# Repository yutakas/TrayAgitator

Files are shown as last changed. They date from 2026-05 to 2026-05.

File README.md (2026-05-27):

# TrayAgitator

A timer-controlled **tray agitator** driven by an ESP32-S3 and a stepper motor.
It runs the motor in an intermittent **2 s on / 8 s off** cycle for a set
duration, with adjustable agitation strength, a countdown timer, an OLED UI, and
buzzer feedback — handy for tasks like film/print development, PCB etching, or
staining where a tray needs gentle, periodic agitation.

## Features

- **Countdown timer** settable in 10-second, minute, and hour steps (up to 5 h).
- **Adjustable strength** (0–4) — controls the stepper's step rate.
- **Intermittent agitation**: the motor rotates ~2 s, then rests ~8 s, repeating
  for the whole run.
- **OLED UI** (SSD1306 128×64) showing mode, time, strength, and chip temperature.
- **DONE screen**: when the timer finishes it shows `DONE!` and counts up the
  time elapsed since it finished; press START to reset.
- **Cancel gesture**: hold MODE + START together to stop a running timer.
- **Persistent settings**: timer and strength are saved to NVS and restored on boot.
- **Boot diagnostics**: shows the last reset reason (and whether a run was active)
  on the OLED and serial, to help track down power/reboot issues. WiFi is disabled
  to reduce power spikes.

## Hardware

- **MCU:** Waveshare **ESP32-S3 Zero** (powered from USB-C, 5 V; 3V3 taken from its
  3V3 pad for the OLED and driver logic).
- **Stepper driver:** **A4988** (motor supply `VMOT` = 8–35 V, e.g. 12 V, with a
  100 µF cap across VMOT–GND).
- **Motor:** bipolar 4-wire NEMA-style stepper.
- **Display:** SSD1306 OLED, 128×64, I²C @ `0x3C`.
- **Buzzer:** passive buzzer.
- **Input:** 4 push buttons (`INPUT_PULLUP`, 50 ms debounce).

### Pin map

| GPIO | Function | Connects to |
|---|---|---|
| 3 | UP button | button → GND |
| 4 | DOWN button | button → GND |
| 5 | MODE button | button → GND |
| 6 | START button | button → GND |
| 7 | Buzzer | passive buzzer + GND |
| 8 | I²C SDA | OLED SDA |
| 9 | I²C SCL | OLED SCL |
| 10 | Stepper STEP | A4988 STEP |
| 11 | Stepper DIR | A4988 DIR |
| 12 | Stepper ENABLE  | A4988 EN (see note) |

**Wiring notes**

- All grounds must be common: ESP32 GND, A4988 logic GND, motor-supply (−), OLED,
  buzzer, and button returns.
- The A4988 `EN` pin is active-LOW on the chip, but the firmware drives EN **HIGH
  to run** / LOW to idle — verify your physical EN wiring/logic matches.
- Tie A4988 `RESET` to `SLEEP`; set `MS1/MS2/MS3` for the desired microstep mode.
- The MODE button idles LOW while the others idle HIGH (per a firmware comment) —
  confirm that switch's normally-open/closed wiring.

See [Documents/](Documents/) for the full diagrams:
[wiring](Documents/TrayAgitator-wiring.svg),
[schematic](Documents/TrayAgitator-schematic.svg) (KiCad source
`TrayAgitator.kicad_sch`), and the `TrayAgitator Build Doc.docx`.

## Controls

- **MODE** cycles the setting screen: `Set 10 sec` → `Set Min` → `Set Hours` →
  `Strength`.
- **UP / DOWN** adjust the current setting (only while the timer is stopped):
  time by 10 s / 1 min / 1 h, or strength 0–4.
- **START**:
  - stopped → start the run (if a time is set)
  - running → pause
  - paused → resume
  - done → acknowledge and return to the setting screen
- **MODE + START (held together)** → cancel a running/paused timer.

## Build & flash

The firmware lives in [ESP32_Source/](ESP32_Source/) and builds with
[PlatformIO](https://platformio.org/).

```bash
cd ESP32_Source
pio run            # build
pio run -t upload  # flash over USB (serial/esptool — more reliable than JTAG)
pio device monitor # serial monitor @ 115200
```

- **Environment:** `esp32-s3-devkitc-1` (Arduino framework), used as the build
  target for the S3 board.
- **Key dependencies** (auto-installed by PlatformIO): Adafruit SSD1306,
  ezButton, AccelStepper. See [ESP32_Source/platformio.ini](ESP32_Source/platformio.ini).

> On macOS, prefer `pio run -t upload` (serial) over JTAG programming — the
> built-in USB-JTAG can be unreliable for flashing.

## Project structure

```
TrayAgitator/
├── ESP32_Source/        # PlatformIO firmware project
│   ├── src/main.cpp     # all firmware logic
│   └── platformio.ini   # board / build config
├── Documents/           # KiCad schematic, wiring/schematic SVGs, build doc
└── README.md
```

## Notes

- The current build **pauses at boot** on the reset-reason screen until a button
  is pressed — this is a debugging aid and can be removed for normal use.
- Some warmth on the chip-temperature readout is normal (it reads the silicon die
  temperature, above ambient).

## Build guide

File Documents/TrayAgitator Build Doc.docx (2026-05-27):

ESP32 Pins

Pin3 Up button

Pin4 Down Button

Pin5 Mode Button

Pin6 Start Button

Pin8 I2C SDA

Pin9 I2C SCL

ESP32 S3 Zero

https://www.waveshare.com/wiki/ESP32-S3-Zero

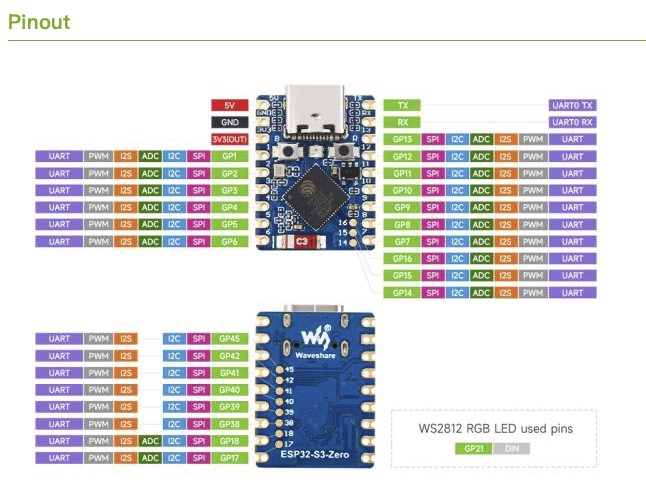
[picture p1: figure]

Motor Driver Tutrial

https://www.makerguides.com/a4988-stepper-motor-driver-arduino-tutorial/

A4988 Stepper Motor Controller

https://www.pololu.com/product/1182

Stepper Motor code

https://randomnerdtutorials.com/esp32-stepper-motor-28byj-48-uln2003/

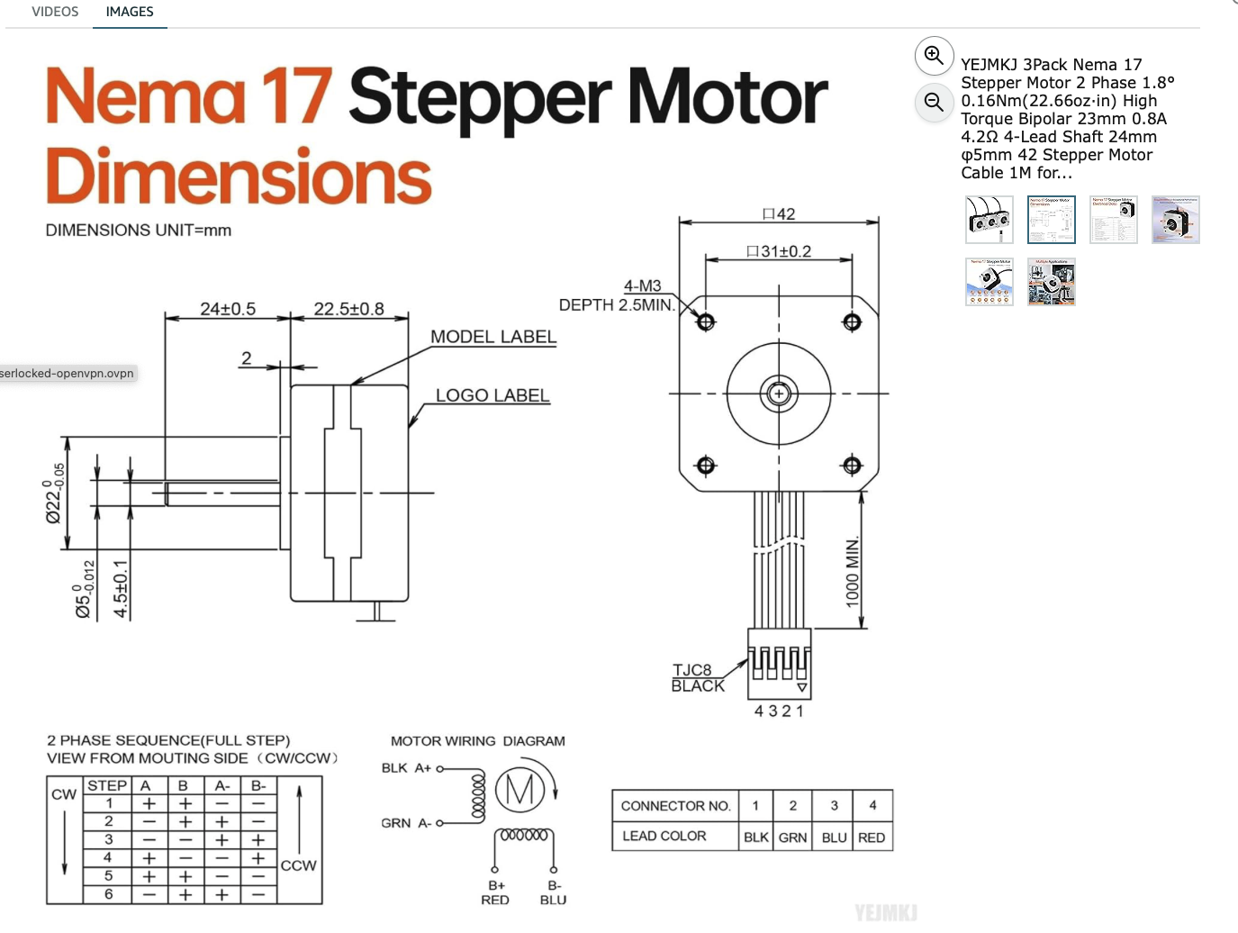
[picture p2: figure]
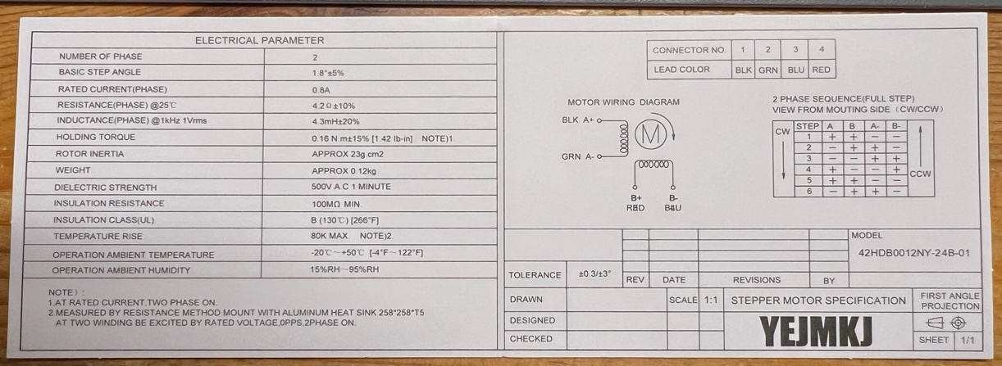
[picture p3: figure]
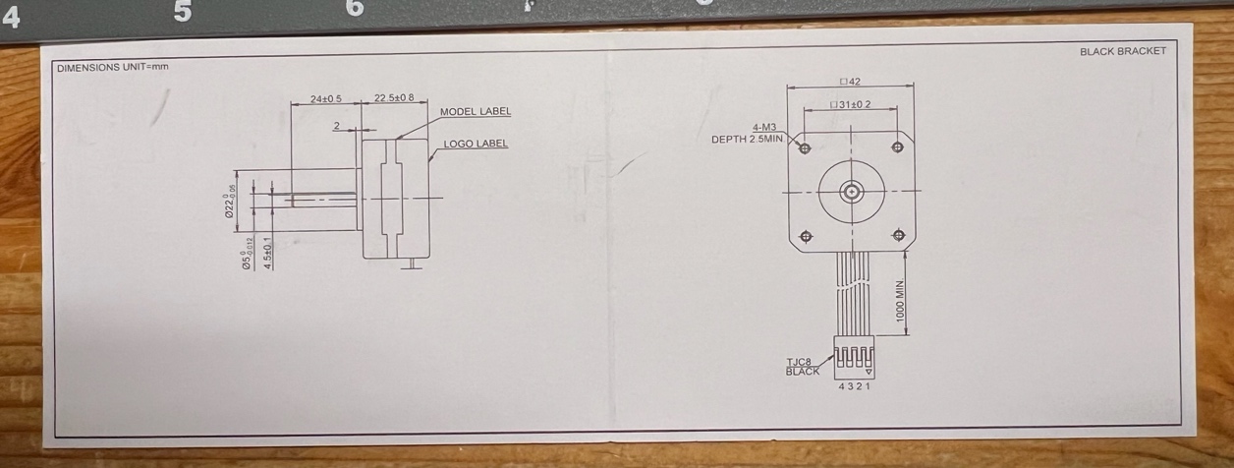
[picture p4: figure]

Beep

https://docs.sunfounder.com/projects/esp32-starter-kit/en/latest/arduino/basic_projects/ar_ac_buz.html

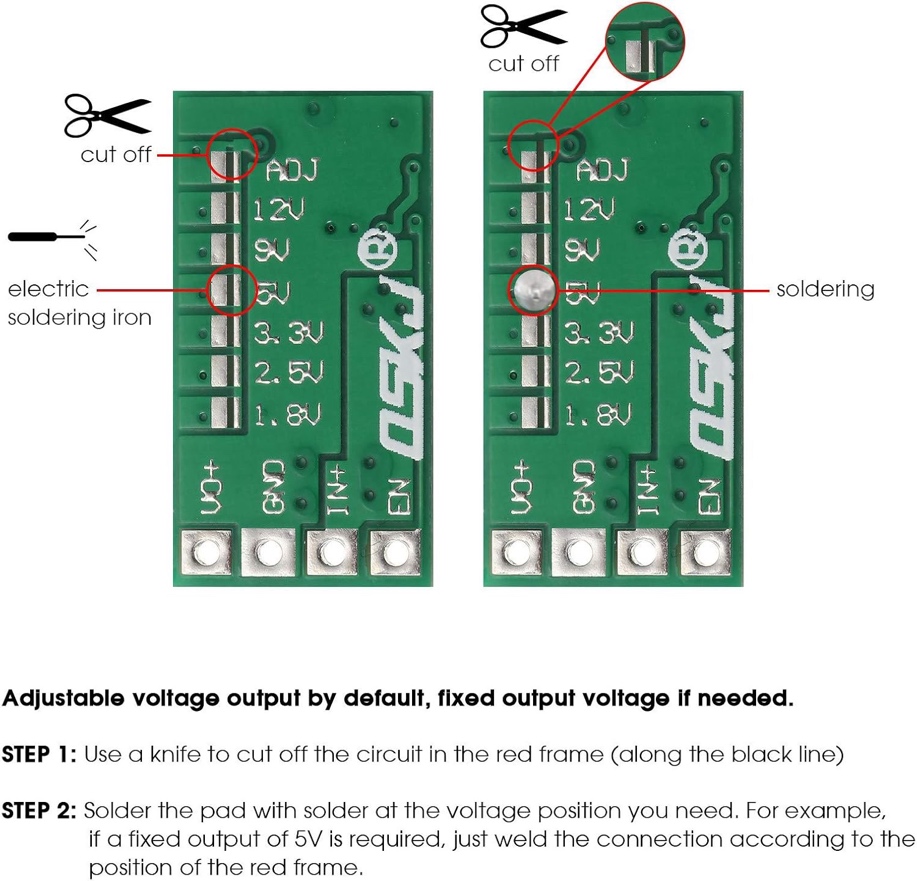
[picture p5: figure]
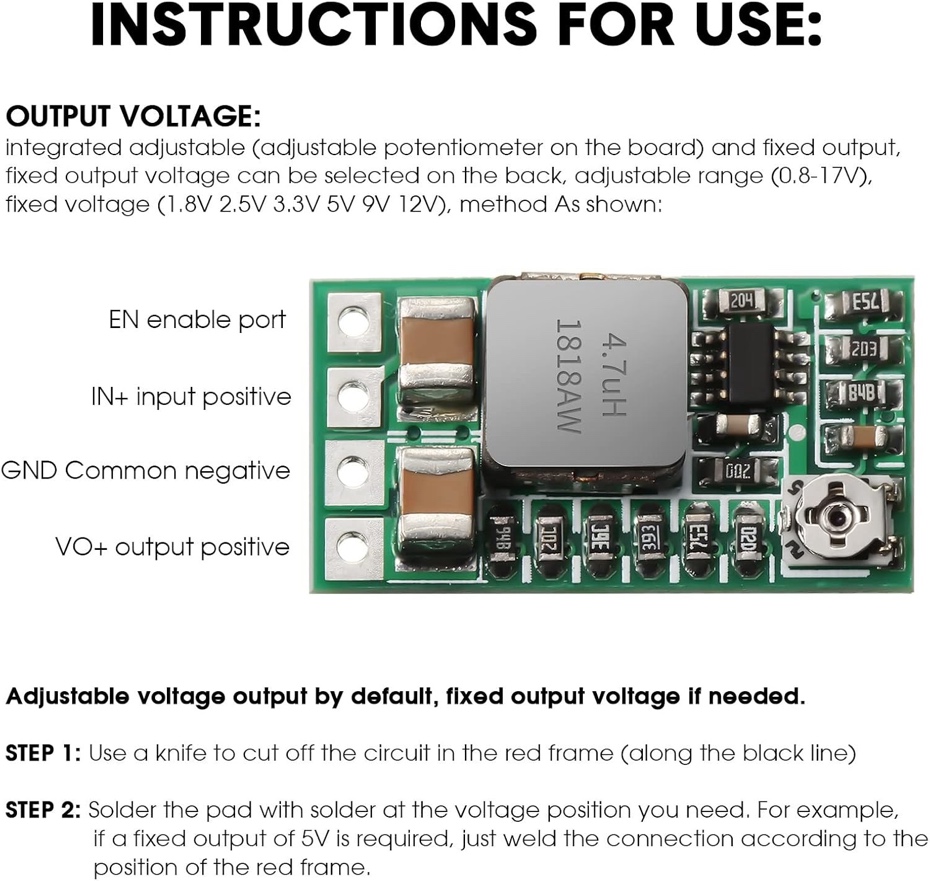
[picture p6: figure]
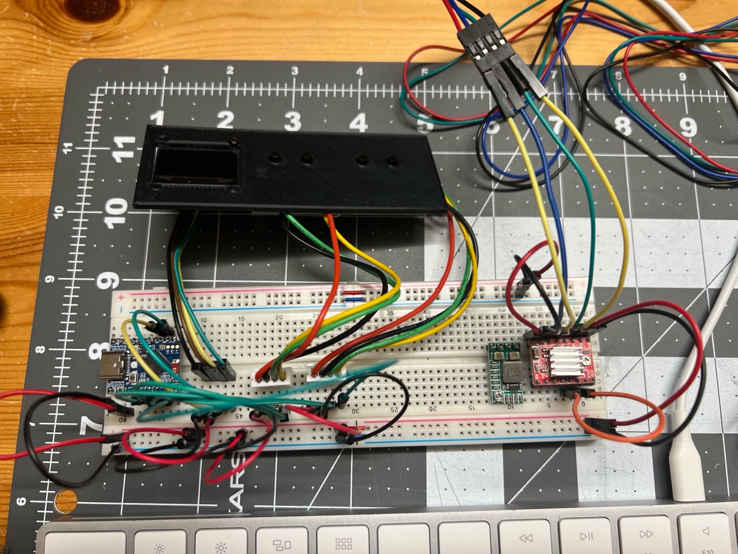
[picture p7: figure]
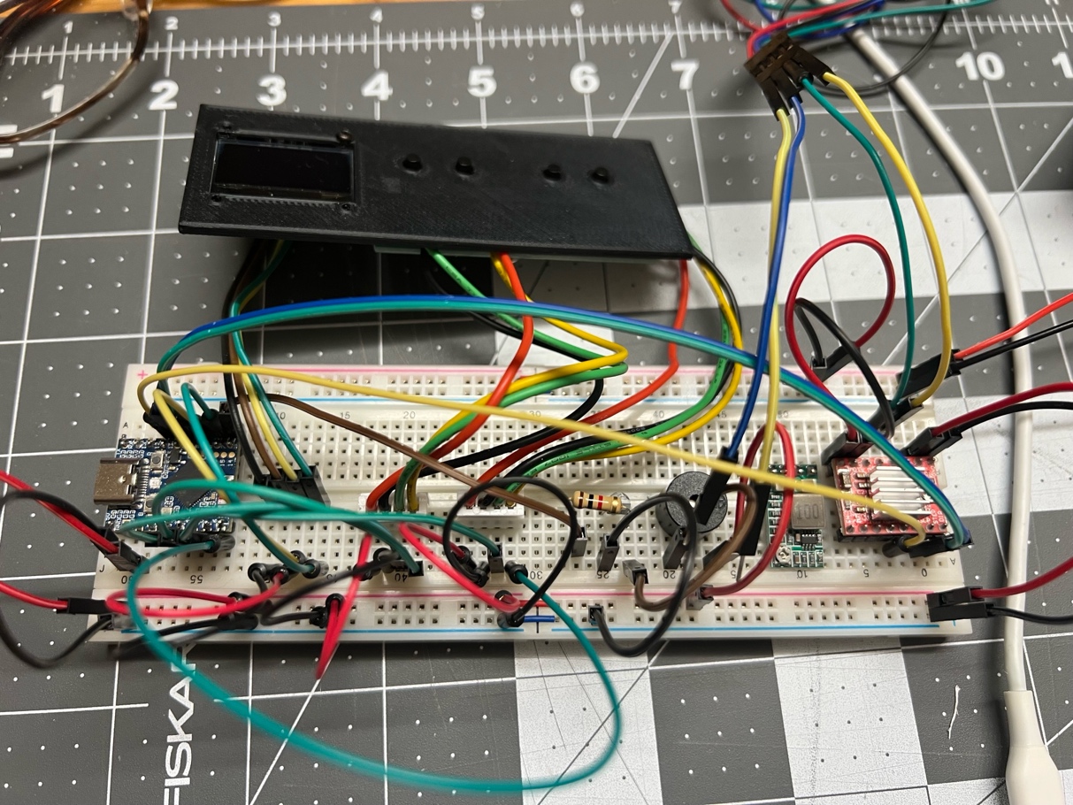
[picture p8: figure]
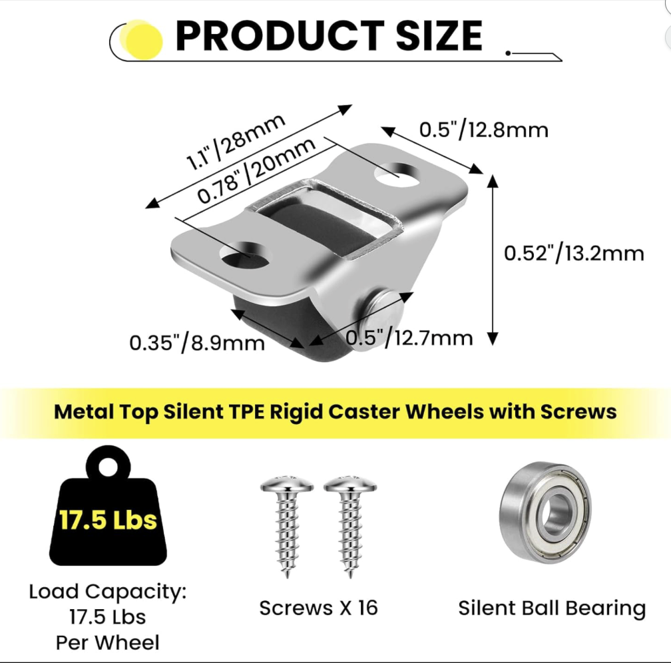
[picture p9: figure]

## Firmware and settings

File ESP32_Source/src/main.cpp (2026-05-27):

#include <Arduino.h>
#include <WiFi.h>

#include <Wire.h>
#include <Adafruit_GFX.h>
#include <Adafruit_SSD1306.h>

#include <ezButton.h>
#include <Preferences.h>
#include <esp_system.h>

Preferences prefs;

#define PIN_1 1
#define PIN_2 2
#define PIN_3 3
#define PIN_4 4
#define PIN_5 5
#define PIN_6 6
#define PIN_7 7
#define PIN_8 8
#define PIN_9 9
#define PIN_10 10 
#define PIN_11 11
#define PIN_12 12
#define PIN_13 13
#define PIN_14 14
#define PIN_15 15

#define SETMODE_STRENGTH4      4
#define SETMODE_HOURS          3
#define SETMODE_MINUTES        2
#define SETMODE_10SEC          1

int currentSetMode = SETMODE_10SEC;
int32_t timerSetTime = 0;

#define MAX_STRENGTH_LEVEL 4
int currentStrengthLevel = 0;


#define SCREEN_WIDTH 128 // OLED display width, in pixels
#define SCREEN_HEIGHT 64 // OLED display height, in pixels

// Declaration for an SSD1306 display connected to I2C (SDA, SCL pins)
Adafruit_SSD1306 display(SCREEN_WIDTH, SCREEN_HEIGHT, &Wire, -1);


ezButton button_up(PIN_3);
ezButton button_down(PIN_4);
ezButton button_mode(PIN_5);
ezButton button_start(PIN_6);

int timeCurrentRemained = 0;
unsigned long startMillis = 0; 
unsigned long pausedMillis = 0;
#define TIMERSTATUS_RUNNING 2
#define TIMERSTATUS_PAUSED 1
#define TIMERSTATUS_STOPPED 0
#define TIMERSTATUS_DONE 3
int fTimerRunning = TIMERSTATUS_STOPPED;
unsigned long doneMillis = 0; // millis() when the timer finished, for the count-up on the DONE screen
bool cancelGestureHandled = false;




// functins for BEEP
#define LEDC_CHANNEL_FOR_BEEP 0
void beep_start();
void beep_stop();
void beep_run();
void beep_short();
void upadteDisplay();
void setSessionActiveFlag(bool active);



#define STEPPER_STEP_PIN PIN_10
#define STEPPER_DIRECT_PIN PIN_11
#define STEPPER_ENABLE_PIN PIN_12

int pulseWidthMicros = 20;  // microseconds
int stepIntervalMicros = 1000; // base interval at max strength (1ms = 1000µs)

//--- test direct control of stepper motor ---
void testStepperDirectControl() {
  Serial.println("Start testStepperDirectControl");
  int numberOfSteps = 1000;

  digitalWrite(STEPPER_DIRECT_PIN, HIGH);
  digitalWrite(STEPPER_ENABLE_PIN, HIGH); 

  for(int n = 0; n < numberOfSteps; n++) {
    digitalWrite(STEPPER_STEP_PIN, HIGH);
    delayMicroseconds(pulseWidthMicros); // this line is probably unnecessary
    digitalWrite(STEPPER_STEP_PIN, LOW);
    
    delayMicroseconds(stepIntervalMicros);
    
    // digitalWrite(ledPin, !digitalRead(ledPin));
  }
  // digitalWrite(stepPin, HIGH);
  // delay(2000);
  digitalWrite(STEPPER_ENABLE_PIN, LOW); 
  Serial.println("End testStepperDirectControl");
}


// Human-readable last-reset cause. Diagnoses standalone reboots (no USB needed):
// BROWNOUT = power sag, PANIC = firmware crash, *WDT = a hang/lockup.
const char* resetReasonStr(esp_reset_reason_t r) {
  switch (r) {
    case ESP_RST_POWERON:   return "Power-on";
    case ESP_RST_EXT:       return "Ext reset";
    case ESP_RST_SW:        return "SW reset";
    case ESP_RST_PANIC:     return "PANIC/crash";
    case ESP_RST_INT_WDT:   return "Int WDT";
    case ESP_RST_TASK_WDT:  return "Task WDT";
    case ESP_RST_WDT:       return "Other WDT";
    case ESP_RST_DEEPSLEEP: return "Deep sleep";
    case ESP_RST_BROWNOUT:  return "BROWNOUT";
    case ESP_RST_SDIO:      return "SDIO";
    default:                return "Unknown";
  }
}

//--- SETUP and LOOP ---
// the setup function runs once when you press reset or power the board
void setup() {
  Serial.begin(115200);

  // Restore saved settings from NVS
  prefs.begin("agitator", true); // read-only
  timerSetTime = prefs.getInt("timerSetTime", 0);
  currentStrengthLevel = prefs.getInt("strengthLevel", 0);
  int sessionWasActive = prefs.getInt("sessionOn", 0); // was a run in progress at last reset?
  prefs.end();

  WiFi.mode(WIFI_OFF);

  // Initialize the LED pin as an output
  // pinMode(ledPin, OUTPUT);
  pinMode(STEPPER_ENABLE_PIN, OUTPUT);
  digitalWrite(STEPPER_ENABLE_PIN, LOW); 

  // buzzzer pin
  ledcSetup(LEDC_CHANNEL_FOR_BEEP, 2000, 8); // Channel 1, 2kHz, 8-bit resolution
  ledcAttachPin(PIN_7, LEDC_CHANNEL_FOR_BEEP); // Attach the pin to a channel

  // I2C setup
  Wire.begin();
  Wire.setPins(PIN_8, PIN_9);

  if(!display.begin(SSD1306_SWITCHCAPVCC, 0x3C)) { // Address 0x3D for 128x64
    Serial.println(F("SSD1306 allocation failed"));
    for(;;);
  }

  delay(1000);

  // Report why the board last reset so standalone reboots can be diagnosed
  // without a USB/serial connection, plus whether a run was active at the time.
  esp_reset_reason_t resetReason = esp_reset_reason();
  Serial.printf("Last reset reason: %d (%s), session active: %d\n",
                resetReason, resetReasonStr(resetReason), sessionWasActive);

  // No run is in progress immediately after boot, so clear the flag now; it only
  // returns to 1 once a real session starts. Keeps the next reading accurate.
  setSessionActiveFlag(false);

  display.clearDisplay();
  display.setTextColor(WHITE);
  display.setTextSize(1);
  display.setCursor(0, 0);
  display.println("Last reset:");
  display.setTextSize(2);
  display.setCursor(0, 14);
  display.println(resetReasonStr(resetReason));
  display.setTextSize(1);
  display.setCursor(0, 38);
  display.print("When: ");
  display.println(sessionWasActive ? "MOTOR RUNNING" : "idle");
  display.setCursor(0, 52);
  display.println("Press any button");
  display.display();

  button_up.setDebounceTime(50);
  button_down.setDebounceTime(50);
  button_mode.setDebounceTime(50);
  button_start.setDebounceTime(50);

  // Hold on the reset-reason screen until the user acknowledges with a button,
  // so a reboot that happens unattended can't scroll past before it's read.
  for (;;) {
    button_up.loop();
    button_down.loop();
    button_mode.loop();
    button_start.loop();
    if (button_up.isPressed()    || button_up.isReleased()    ||
        button_down.isPressed()  || button_down.isReleased()  ||
        button_mode.isPressed()  || button_mode.isReleased()  ||
        button_start.isPressed() || button_start.isReleased()) {
      break;
    }
    delay(10);
  }

  upadteDisplay();

  pinMode(STEPPER_DIRECT_PIN, OUTPUT);
  pinMode(STEPPER_STEP_PIN, OUTPUT);

  // testStepperDirectControl();
}



//--- Persist settings to NVS ---
void savePrefs() {
  prefs.begin("agitator", false); // read-write
  prefs.putInt("timerSetTime", timerSetTime);
  prefs.putInt("strengthLevel", currentStrengthLevel);
  prefs.end();
}

// Persist whether an agitation session is active. On the next boot setup() reads
// this back so a power-loss reset can be correlated with motor activity: if it's
// still 1, the board died mid-run (NVS is wiped to 0 cleanly on stepper_stop()).
// NVS skips writes when the value is unchanged, so wear stays negligible.
void setSessionActiveFlag(bool active) {
  prefs.begin("agitator", false); // read-write
  prefs.putInt("sessionOn", active ? 1 : 0);
  prefs.end();
}

//--- BEEP functions ---
bool fBeepRunning = false;
unsigned long beepStartMillis = 0;
unsigned long beepDurationMillis = 500; //2000;
void beep_start() {
  ledcWriteTone(LEDC_CHANNEL_FOR_BEEP, 440 * 2); // Play 880 Hz tone
  beepStartMillis = millis();
  fBeepRunning = true;
}

void beep_stop() {
  ledcWriteTone(LEDC_CHANNEL_FOR_BEEP, 0);
  fBeepRunning = false;
} 

void beep_run() {
  if (fBeepRunning) {
    unsigned long currentMillis = millis();
    if (currentMillis - beepStartMillis >= beepDurationMillis) {
      // Stop the beep
      beep_stop();
    }
  }
}

void beep_short() {
  ledcWriteTone(LEDC_CHANNEL_FOR_BEEP, 440 * 4);
  delay(50);
  ledcWriteTone(LEDC_CHANNEL_FOR_BEEP, 0);
}

//--- Update Display ---
void upadteDisplay() {
  char buffer [32];
  display.clearDisplay();
  display.setTextColor(WHITE);

  // DONE screen: big "DONE!" plus a count-up of how long it's been since the timer finished.
  if (fTimerRunning == TIMERSTATUS_DONE) {
    display.setTextSize(2);
    display.setCursor(0, 0);
    display.println("DONE!");

    display.setTextSize(1);
    display.setCursor(0, 22);
    display.println("since done:");

    unsigned long elapsedSec = (millis() - doneMillis) / 1000UL;
    int eh = elapsedSec / 3600;
    int em = (elapsedSec % 3600) / 60;
    int es = elapsedSec % 60;
    display.setTextSize(2);
    display.setCursor(0, 32);
    sprintf(buffer, "+%02d:%02d:%02d", eh, em, es);
    display.println(buffer);

    display.setTextSize(1);
    display.setCursor(0, 56);
    display.println("START = reset");

    display.display();
    return;
  }

  display.setTextSize(2); // main UI is size 2; set explicitly so earlier screens don't leak state

  if (fTimerRunning == TIMERSTATUS_STOPPED) {
    display.setCursor(0, 0);
    switch (currentSetMode) {
      case SETMODE_10SEC:
        display.println("Set 10 sec");
        break;
      case SETMODE_MINUTES:
        display.println("Set Min");
        break;
      case SETMODE_HOURS:
        display.println("Set Hours");
        break;            
      case SETMODE_STRENGTH4:
        display.println("Strength");
        break;
    }

    display.setCursor(0, 18);
    int hours = timerSetTime / 3600;
    int minutes = (timerSetTime % 3600) / 60;
    int seconds = timerSetTime % 60;
    sprintf(buffer, "%02d:%02d:%02d", hours, minutes, seconds);
    display.println(buffer);
  } else {
    display.setCursor(0, 0);
    if (fTimerRunning == TIMERSTATUS_RUNNING) {
      display.println("Running");
    } else if (fTimerRunning == TIMERSTATUS_PAUSED) {
      display.println("Paused");
    }

    display.setCursor(0, 18);
    int hours = timeCurrentRemained / 3600;
    int minutes = (timeCurrentRemained % 3600) / 60;
    int seconds = timeCurrentRemained % 60;
    sprintf(buffer, "%02d:%02d:%02d", hours, minutes, seconds);
    display.println(buffer);    
  }

  display.setTextSize(1);
  display.setCursor(0, 40);
  sprintf(buffer, "Strength %d", currentStrengthLevel);
  display.println(buffer);
 
  // Internal chip die temperature on the bottom row (small). Trend gauge only:
  // reads the silicon temp (warmer than ambient), accuracy ~+/-2-3 C.
  display.setTextSize(1);
  display.setCursor(0, 56);
  sprintf(buffer, "Chip %.1fC", temperatureRead());
  display.println(buffer);

  display.display();
}

bool fStepperRunning = false;
unsigned long stepperLastRunMicros = 0;
unsigned long stepperCycleStartMillis = 0;
bool stepperInRestPhase = false;

#define STEPPER_RUN_MS  2000
#define STEPPER_REST_MS 8000

void stepper_start() {
  setSessionActiveFlag(true);  // record "run active" before energizing the coils
  stepperLastRunMicros = micros();
  stepperCycleStartMillis = millis();
  stepperInRestPhase = false;
  fStepperRunning = true;
  digitalWrite(STEPPER_DIRECT_PIN, LOW);
  digitalWrite(STEPPER_ENABLE_PIN, HIGH);
}

void stepper_stop() {
  fStepperRunning = false;
  stepperInRestPhase = false;
  digitalWrite(STEPPER_ENABLE_PIN, LOW);
  setSessionActiveFlag(false);  // clean stop: clear the flag after de-energizing
}

void stepper_run() {
  if (fStepperRunning) {
    unsigned long elapsed = millis() - stepperCycleStartMillis;

    if (stepperInRestPhase) {
      if (elapsed >= STEPPER_REST_MS) {
        // Rest phase over, start rotating
        stepperInRestPhase = false;
        stepperCycleStartMillis = millis();
        stepperLastRunMicros = micros();
        digitalWrite(STEPPER_ENABLE_PIN, HIGH);
      }
    } else {
      if (elapsed >= STEPPER_RUN_MS) {
        // Run phase over, start resting
        stepperInRestPhase = true;
        stepperCycleStartMillis = millis();
        digitalWrite(STEPPER_ENABLE_PIN, LOW);
      } else {
        // Stepping
        unsigned long currentMicros = micros();
        unsigned long interval = stepIntervalMicros + (MAX_STRENGTH_LEVEL - currentStrengthLevel) * 200UL;
        if (currentMicros - stepperLastRunMicros >= interval) {
          stepperLastRunMicros = currentMicros;
          digitalWrite(STEPPER_STEP_PIN, HIGH);
          delayMicroseconds(pulseWidthMicros);
          digitalWrite(STEPPER_STEP_PIN, LOW);
        }
      }
    }
  }
} 

// the loop function runs over and over again forever
void loop() {
  bool fUpdateDisplay = false;
  unsigned long currentMillis = millis();

  // Refresh ~1x/sec so the chip-temperature readout updates even while idle
  // (during a run the countdown already forces a redraw each second).
  static unsigned long lastPeriodicRefresh = 0;
  if (currentMillis - lastPeriodicRefresh >= 1000) {
    lastPeriodicRefresh = currentMillis;
    fUpdateDisplay = true;
  }

  button_start.loop();
  button_down.loop();
  button_up.loop();
  button_mode.loop();
  beep_run();


  stepper_run();

  // Track physical button hold state using edge events
  // PIN_5 (mode) rests LOW: isReleased()=physical press, isPressed()=physical release
  // PIN_6 (start) rests HIGH: isPressed()=physical press, isReleased()=physical release
  static bool startHeld = false;
  static bool modeHeld = false;

  if (button_start.isPressed()) { startHeld = true; Serial.printf("[BTN] start HELD (modeHeld=%d cancelFlag=%d timer=%d)\n", modeHeld, cancelGestureHandled, fTimerRunning); fUpdateDisplay = true; }
  if (button_start.isReleased()) { startHeld = false; Serial.printf("[BTN] start FREE (modeHeld=%d cancelFlag=%d timer=%d)\n", modeHeld, cancelGestureHandled, fTimerRunning); }
  if (button_mode.isReleased()) { modeHeld = true; Serial.printf("[BTN] mode  HELD (startHeld=%d cancelFlag=%d timer=%d)\n", startHeld, cancelGestureHandled, fTimerRunning); }
  if (button_mode.isPressed()) { modeHeld = false; Serial.printf("[BTN] mode  FREE (startHeld=%d cancelFlag=%d timer=%d)\n", startHeld, cancelGestureHandled, fTimerRunning); }
  if (button_up.isReleased()) { Serial.println("[BTN] up    HELD"); fUpdateDisplay = true; }
  if (button_up.isPressed()) { Serial.println("[BTN] up    FREE"); }
  if (button_down.isReleased()) { Serial.println("[BTN] down  HELD"); fUpdateDisplay = true; }
  if (button_down.isPressed()) { Serial.println("[BTN] down  FREE"); }

  // Cancel timer: both mode + start physically held simultaneously
  if (startHeld && modeHeld) {
    if (!cancelGestureHandled && fTimerRunning != TIMERSTATUS_STOPPED) {
      Serial.println("[CANCEL] fired");
      fTimerRunning = TIMERSTATUS_STOPPED;
      stepper_stop();
      beep_short();
      fUpdateDisplay = true;
      cancelGestureHandled = true;
    }
  }
  // Reset cancel flag once both buttons are physically released and no pending events
  if (cancelGestureHandled && !startHeld && !modeHeld
      && !button_start.isReleased() && !button_mode.isPressed()) {
    Serial.println("[CANCEL] flag reset");
    cancelGestureHandled = false;
  }

  if(button_start.isReleased() && !cancelGestureHandled) {
    Serial.printf("[ACTION] start toggle (timer=%d)\n", fTimerRunning);

    if (fTimerRunning == TIMERSTATUS_STOPPED) {
      if (timerSetTime > 0) {
        fTimerRunning = TIMERSTATUS_RUNNING;
        startMillis = millis();
        pausedMillis = -1;
        timeCurrentRemained = timerSetTime;
        beep_short();
        stepper_start();
      }
    } else if (fTimerRunning == TIMERSTATUS_RUNNING) {
      fTimerRunning = TIMERSTATUS_PAUSED;
      pausedMillis= millis();
      stepper_stop();
      beep_short();
    } else  if (fTimerRunning == TIMERSTATUS_PAUSED) {
      fTimerRunning = TIMERSTATUS_RUNNING;
      stepper_start();
      beep_short();
    } else if (fTimerRunning == TIMERSTATUS_DONE) {
      // Acknowledge the done screen and return to the setup screen
      fTimerRunning = TIMERSTATUS_STOPPED;
      beep_short();
    }
    fUpdateDisplay = true;
  }

  if(button_up.isPressed()) {
    Serial.println("The button_up is pressed");
    fUpdateDisplay = true;
  }

  if(button_up.isReleased()) {
    Serial.println("The button_up is released");
    if (fTimerRunning == false) {
        switch (currentSetMode) {
          case SETMODE_10SEC:
            timerSetTime += 10;
            beep_short();
            break;
          case SETMODE_MINUTES:
            timerSetTime += 60;
            beep_short();
            break;
          case SETMODE_HOURS:
            timerSetTime += 3600;
            beep_short();
            break;            
          case SETMODE_STRENGTH4:
            currentStrengthLevel++;
            if (currentStrengthLevel > MAX_STRENGTH_LEVEL) {
              currentStrengthLevel = MAX_STRENGTH_LEVEL;
            }
            beep_short();
            break;
        } 
        if (timerSetTime >= 3600 * 5) {
          timerSetTime = 3600 * 5;
        }
        savePrefs();
        fUpdateDisplay = true;
    }
  }

  if(button_down.isPressed()) {
    Serial.println("The button_down is pressed");
    fUpdateDisplay = true;
  }

  if(button_down.isReleased()) {
    Serial.println("The button_down is released");
    if (fTimerRunning == false) {
        switch (currentSetMode) {
          case SETMODE_10SEC:
            timerSetTime -= 10;
            beep_short();
            break;
          case SETMODE_MINUTES:
            timerSetTime -= 60;
            beep_short();
            break;
          case SETMODE_HOURS:
            timerSetTime -= 3600;
            beep_short();
            break;
          case SETMODE_STRENGTH4:
            currentStrengthLevel--;
            if (currentStrengthLevel < 0) {
              currentStrengthLevel = 0;
            }
            beep_short();
            break;
        }
        if (timerSetTime < 0) {
          timerSetTime = 0;
        }
        savePrefs();
        fUpdateDisplay = true;
    }
  }
  if(button_mode.isPressed()) {
    Serial.println("The button_mode is pressed");
    fUpdateDisplay = true;
  }

  if(button_mode.isReleased() && !cancelGestureHandled) {
    Serial.println("The button_mode is released");
    currentSetMode++;
    if (currentSetMode > SETMODE_STRENGTH4) {
      currentSetMode = SETMODE_10SEC;
    }
    beep_short();
  }

  if (fTimerRunning == TIMERSTATUS_RUNNING) {
    if (pausedMillis != -1) {
      startMillis += (millis() - pausedMillis);
      pausedMillis = -1;
    }
    int newTimeRemained = timerSetTime - (int)((millis() - startMillis) / 1000.0);
    if (newTimeRemained <= 0) {
      timeCurrentRemained = 0;
      fTimerRunning = TIMERSTATUS_DONE;
      doneMillis = millis();
      stepper_stop();
      fUpdateDisplay = true;
      beep_start();
    } else if (newTimeRemained != timeCurrentRemained) {
      timeCurrentRemained = newTimeRemained;
      fUpdateDisplay = true;
    }
  }

  if (fUpdateDisplay) {
    upadteDisplay();
  }


}

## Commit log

2025-12-27 the first timer code
2025-12-31 use stepper motor
2025-12-31 doc with beep wiring
2025-12-31 use ledc library
2026-01-04 stepper motor Nema17
2026-02-19 smoother stepper and persist settings
    - Switch stepper timing from millis() to micros() for finer step intervals
    - Save timerSetTime and currentStrengthLevel to NVS via Preferences
    - Restore saved values on boot
2026-04-14 add cancel timer by pressing both mode + start buttons
    Use edge-based button tracking instead of getState() for cancel
    detection, since mode/up/down pins (PIN_3/4/5) rest LOW and
    getState() falsely reads them as pressed. Added 50ms debounce
    to all buttons.
2026-04-14 stepper runs 2s on / 8s off cycle instead of continuous
2026-05-26 add new documents
    [.kicad_sch, .kicad_sch.kicad_sch, TrayAgitator.kicad_sch]
2026-05-26 add boot diagnostics: reset reason, session flag, chip temp on OLED
    Instrument standalone reboots that can't be observed over serial:
    - Show the last reset reason (esp_reset_reason) on the OLED at boot and
    on serial, holding the screen until a button is pressed so unattended
    reboots can't scroll past unseen.
    - Persist a 'session active' flag to NVS on stepper start/stop so a
    power-loss reset can be correlated with motor activity (MOTOR RUNNING
    vs idle) on the next boot.
    - Add a chip die-temperature readout to the main UI, refreshed ~1x/sec
    (forced redraw so it updates even while idle).
    - Set text size explicitly in upadteDisplay so earlier screens no longer
    leak state into the ma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
    [main.cpp]
2026-05-27 add DONE screen with count-up since timer finished
    When the countdown reaches 0 the timer now enters a new TIMERSTATUS_DONE
    state instead of silently returning to the setup screen:
    - OLED shows a big 'DONE!' plus '+HH:MM:SS' counting up since the finish
    time (doneMillis), refreshed once a second.
    - START acknowledges and returns to the setup screen; up/down stay locked
    on the done screen so settings can't change by accident.
    - Completion now triggers on remaining <= 0 (was == 0) so a skipped tick
    still finishes instead of overshooting into negative time.
    [main.cpp]
2026-05-27 add project README
    Document the TrayAgitator: purpose, features, hardware (ESP32-S3 Zero +
    A4988 driver + SSD1306 OLED), full GPIO pin map, controls, and PlatformIO
    build/flash steps. Links to the schematic and wiring diagrams under Documents/.
